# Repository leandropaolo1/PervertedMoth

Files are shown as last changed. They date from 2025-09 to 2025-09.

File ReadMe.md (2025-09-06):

# Perverted Moth – SLINO Design Files

This repository collects the **SLINO design files** and community discussion surrounding the experimental *Perverted Moth* sailing dinghy project.

The SLINO was a home-built International Moth concept — a carbon and foam “plate moth” constructed from router-cut panels and frames, assembled on an MDF jig. The project and build logs were originally shared on [Sailing Anarchy Forums](https://forums.sailinganarchy.com/threads/perverted-moth.89686/) :contentReference[oaicite:0]{index=0} and the [Perverted Moth Blog](http://perverted-moth.blogspot.com/search/label/slino).

---

## Preview

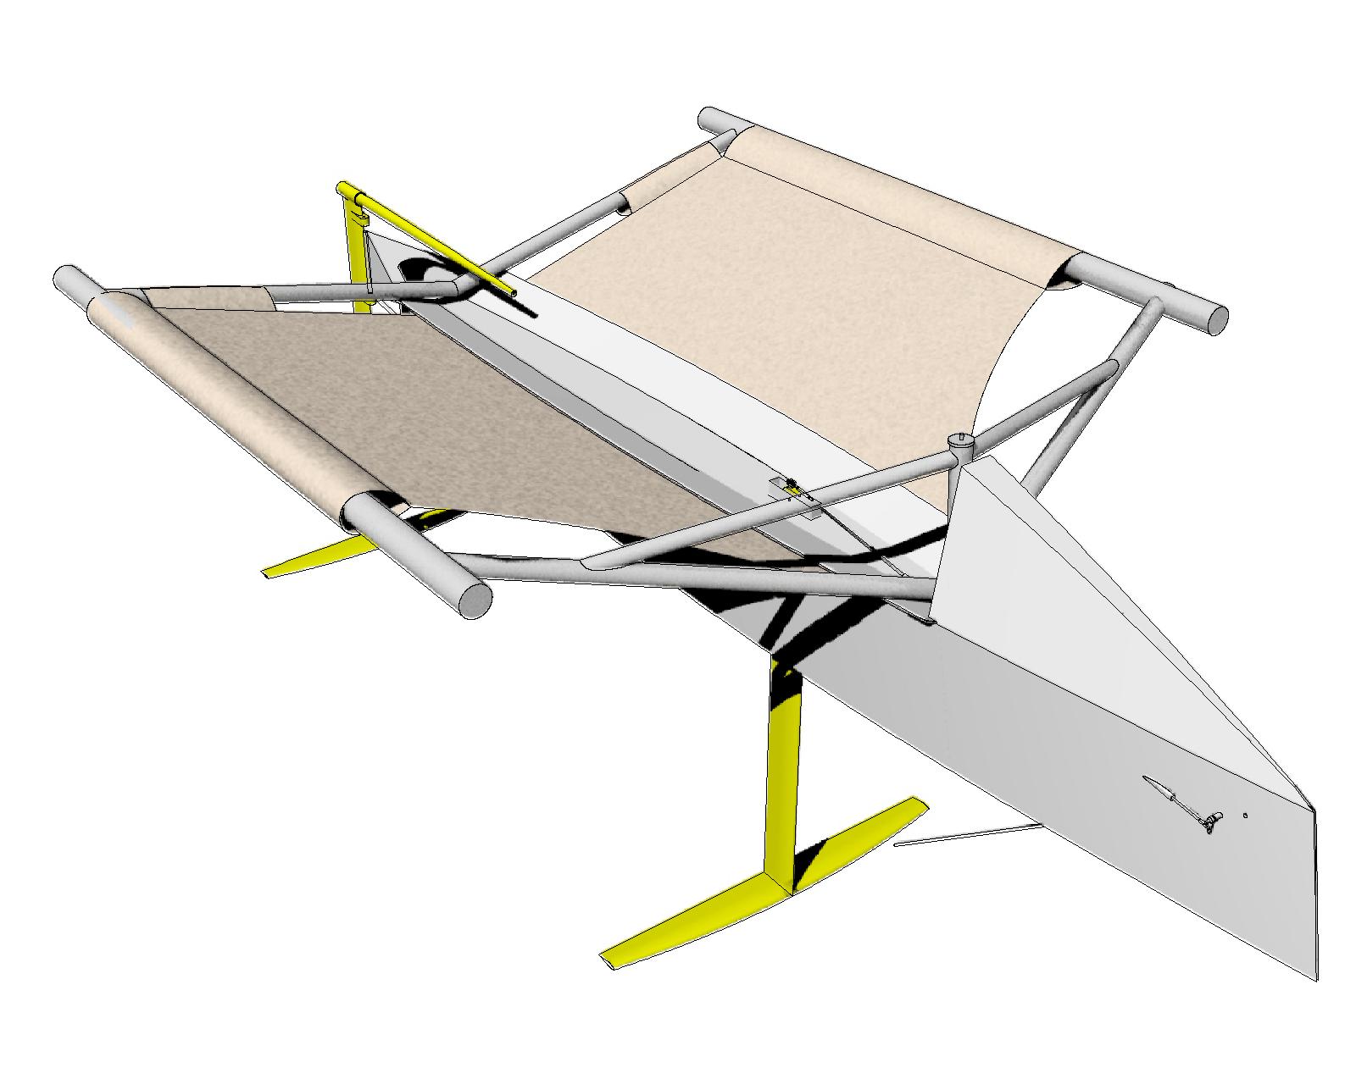
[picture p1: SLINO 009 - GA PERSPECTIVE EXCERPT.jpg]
SLINO GA Perspective Excerpt


*General Arrangement Perspective (excerpt)*

---

## ⚠️ Disclaimer

These files are published as a **personal reference only**.  
They are not guaranteed to be complete, safe, or production-ready.

- **No warranty is provided.**  
- **Use at your own risk.**  
- Building and sailing a moth to this design could seriously hurt you, cost you money, or cause emotional damage:contentReference[oaicite:1]{index=1}.  

If you attempt to replicate or derive from this design, please share your results with the original author (see below).

---

## Contents

The SLINO design package includes:

- **Documents & Calculations**  
  - Build sequence, parts list, weight estimate  
  - Hydrostatics and resistance predictions  

- **Drawings**  
  - Hull lines and construction details  
  - Centreboard, rudder, gantry, spreaders  
  - Wing and control system arrangements  

- **Cut Files & Jig**  
  - Carbon cut files  
  - MDF cut files  
  - Hull and deck panel marking  

- **3D Rhino Models**  
  - Hull construction and jig  
  - Wings, centreboard, rudder  
  - Wing sail, cradle, control system  

---

## References

- Blog archive: [perverted-moth.blogspot.com](http://perverted-moth.blogspot.com/search/label/slino)  
- Forum thread: [Sailing Anarchy – Perverted Moth](https://forums.sailinganarchy.com/threads/perverted-moth.89686/) :contentReference[oaicite:2]{index=2}  
- Original design files post: [SLINO Design Files (2010)](https://perverted-moth.blogspot.com/2010/11/slino-design-files.html) :contentReference[oaicite:3]{index=3}

---

## Contact

The design files were shared by **Markla (n4rkla)**.  
If you experiment with these designs, you are encouraged to send results or build logs to:

📧 **mr.markla@gmail.com**:contentReference[oaicite:4]{index=4}

---

## License

This project is **not licensed** for commercial use.  
Files are provided *as-is* for reference, experimentation, and historical interest.

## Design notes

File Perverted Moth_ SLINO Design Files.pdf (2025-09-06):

Sunday, November 14, 2010

## SLINO Design Files

Please Note:
I am publishing this information as a personal reference only. If you chose to replicate it, it is at your own risk. This information carries no warranty and has not been thoroughly thought through or engineered. Building and sailing a moth to this design could seriously hurt you and/or cost you a lot of money and/or cause emotional damage.

If you do attempt to replicate derivate from this information please send me an email – I am always interested to see where this design leads. (mr.markla@gmail.com)

See Also:
http://perverted-moth.blogspot.com/2009/01/new-moth-design.html

Documents and Calculations
SL2-A1-01A - Drawing and Document List (https://docs.google.com/uc?export=download&authkey=CN-VgPIJ&hl=en)
SL2-A1-02A - SLINO Build Sequence (https://docs.google.com/uc?export=download&authkey=CNLG-LgK&hl=en) SL2-A1-03 - Parts List
SL2-B1-01 - Weight Estimate (https://docs.google.com/open?id=0B2AmITOPvYs3YjllM2UwZjEtNGI4Ni00YWUwLWJhY2EtNWJhNjgxMDQ1ZTFj)
SL2-B2-01 - Table of Hydrostatics (https://docs.google.com/open?id=0B2AmITOPvYs3MDE4MTIzOTItMmE5Zi00ZGQ1LWEzYTUtMzUyZGFhMmE2NmFl) SL2-B2-02 - Resistance Prediction (https://docs.google.com/open?id=0B2AmITOPvYs3OTdkZGM3MGQtNTlhZC00MGI1LTg4NjItY2FhZDk2NGU4MjJh)

Drawings
SL2-C1-01 Side Profile Drawing SL2-C1-02A - General Arrangement (https://docs.google.com/uc?export=download&authkey=CK3E1asO&hl=en)

SL2-D1-01A - Hull Lines Drawing (https://docs.google.com/uc?export=download&authkey=COr-_s8G&hl=en)

SL2-E1-01A - Hull Construction Drawing (https://docs.google.com/uc?export=download&authkey=CNz7gcMD&hl=en) SL2-E1-02__04A - Hull Construction Details (https://docs.google.com/viewer?a=v&pid=explorer&chrome=true&hl=en_US) SL2-E2-01__02A - Centreboard Construction Drawing (https://docs.google.com/viewer?a=v&pid=explorer&chrome=true&hl=en_US) SL2-E3-01 Stem and Transom Lug Construction Details (https://docs.google.com/viewer?a=v&pid=explorer&chrome=true&hl=en_US) SL2-E4-01 Wing Mounts Construction Details (https://docs.google.com/viewer?a=v&pid=explorer&chrome=true&hl=en_US)

SL2-F1-01A - Wing Assembly (https://docs.google.com/uc?export=download&hl=en)
SL2-F2-01A - Gantry Construction Drawing (https://docs.google.com/uc?export=download&authkey=CLfcmI8G&hl=en) SL2-F3-01A - Spreader Construction Drawing (https://docs.google.com/uc?export=download&authkey=CNL18sgL&hl=en) SL2-F4-01A - Running Rigging Arrangement (https://docs.google.com/viewer?a=v&pid=explorer&chrome=true&hl=en_US) SL2-F5-01__02A - Cradle Arrangement (https://docs.google.com/uc?export=download&authkey=CNLH6WQ&hl=en)

SL2-G1-01A - Control System Arrangement (https://docs.google.com/viewer?a=v&pid=explorer&chrome=true&hl=en_US) SL2-G1-02A - Control System Parts (https://docs.google.com/viewer?a=v&pid=explorer&chrome=true&hl=en_US)

Click to jump to the design post.

SLINO

This site has a lot of weird content. If you want to view only posts regarding the design and build of the SLINO design, click the picture.

SLINO FILTER

MARKLA (https://www.blogger.com/profile/16777292264295936655)

n4rkla (https://www.blogger.com/profile/01014271006445643045)

CONTRIBUTORS

- 2017 (https://perverted-moth.blogspot.com/2017/) (1)
- 2015 (https://perverted-moth.blogspot.com/2015/) (3)
- 2014 (https://perverted-moth.blogspot.com/2014/) (3)
- 2013 (https://perverted-moth.blogspot.com/2013/) (19)
- 2012 (https://perverted-moth.blogspot.com/2012/) (18)
- 2011 (https://perverted-moth.blogspot.com/2011/) (21)

▼ 2010 (https://perverted-moth.blogspot.com/2010/) (35)
- December (https://perverted-moth.blogspot.com/2010/12/) (1)

Blog Archive

More | Create Blog (https://www.blogger.com/onboarding) Sign In (https://www.blogger.com/)

Posted by MARKLA (https://www.blogger.com/profile/16777292264295936655) at 8:54 PM (https://perverted-moth.blogspot.com/2010/11/slino-design-files.html) Labels: design, (https://perverted-moth.blogspot.com/search/label/design) slino (https://perverted-moth.blogspot.com/search/label/slino)

SL2-H1-01A - Hull Jig Assembly (https://docs.google.com/uc?export=download&authkey=CKD--tEP&hl=en) SL2-H1-02A - Deck Jig Assembly (https://docs.google.com/uc?export=download&authkey=CNO9yMAD&hl=en) SL2-H1-03A - Foredeck Jig Modification (https://docs.google.com/uc?export=download&authkey=CKOhy74L&hl=en)

SL2-I1-01A - Carbon Cut File (1) SL2-I1-02A - Carbon Cut File (2) (https://docs.google.com/uc?export=download&authkey=CP3i0JYM&hl=en) SL2-I2-01A - MDF Cut File (1) SL2-I2-02A - MDF Cut File (2) (https://docs.google.com/uc?export=download&authkey=CJm_-Y4K&hl=en) SL2-I3-01A - Hull Panel Marking (https://docs.google.com/uc?export=download&authkey=CNnmnr8N&hl=en) SL2-I3-02A - Deck Panel Marking (https://docs.google.com/uc?export=download&authkey=CJjL29gC&hl=en)

Rhino Models
All models have the same zero point, so you can import (or worksession) the components into a single file. SL2-R1-01A - Hull Construction (https://docs.google.com/uc?export=download&authkey=CJyo3bUF&hl=en)
SL2-R1-02A - Hull Jig (https://docs.google.com/uc?export=download&authkey=CMfQ6awO&hl=en)
SL2-R1-03A - Wings (https://docs.google.com/uc?export=download&authkey=CNzQxsgL&hl=en)

SL2-R2-01A - Centreboard (https://docs.google.com/uc?export=download&authkey=CM_9-5oH&hl=en)

SL2-R3-01A - Rudder (https://docs.google.com/uc?export=download&authkey=CJn_7rkB&hl=en)

SL2-R4-01A - Control System (https://docs.google.com/uc?export=download&authkey=CMWgyMQJ&hl=en)

SL2-R5-01A - Wing Sail (https://docs.google.com/uc?export=download&authkey=CIyVoc0M&hl=en)

SL2-R9-01A - Cradle (https://docs.google.com/uc?export=download&authkey=CJiKxfME&hl=en)

## 6 comments:

Anonymous November 15, 2010 at 1:52 PM (https://perverted-moth.blogspot.com/2010/11/slino-design-files.html?showComment=1289793150781)

Very cool! Thanks.

Reply

Anonymous November 16, 2010 at 10:52 AM (https://perverted-moth.blogspot.com/2010/11/slino-design-files.html?showComment=1289868720213)

Funny about the Wing sail link.....

Reply

n4rkla (https://www.blogger.com/profile/01014271006445643045) November 16, 2010 at 9:46 PM (https://perverted-moth.blogspot.com/2010/11/slino-design-files.html?showComment=1289907984469)

oh hardy har har...I'll get you for that pikey

Reply

trentpt17 (https://www.blogger.com/profile/12523880471407403194) July 18, 2011 at 12:41 AM (https://perverted-moth.blogspot.com/2010/11/slino-design-files.html?showComment=1310913688922)

This comment has been removed by the author.

▼ November (https://perverted-moth.blogspot.com/2010/11/) (7)
what would tucker do? (https://perverted-moth.blogspot.com/2010/11/what-would-tucker-do.html)

Hat-trick! (https://perverted-moth.blogspot.com/2010/11/hat-trick.html)

Luka's Lister Boom (https://perverted-moth.blogspot.com/2010/11/lukas-boom.html)

wing rule idea (https://perverted-moth.blogspot.com/2010/11/wing-rule-idea.html)

nick in teh boat (https://perverted-moth.blogspot.com/2010/11/nick-in-teh-boat.html)

Wanted (https://perverted-moth.blogspot.com/2010/11/wanted.html)

SLINO Design Files (https://perverted-moth.blogspot.com/2010/11/slino-design-files.html)

- October (https://perverted-moth.blogspot.com/2010/10/) (2)
- August (https://perverted-moth.blogspot.com/2010/08/) (2)
- July (https://perverted-moth.blogspot.com/2010/07/) (3)
- June (https://perverted-moth.blogspot.com/2010/06/) (2)
- May (https://perverted-moth.blogspot.com/2010/05/) (1)
- April (https://perverted-moth.blogspot.com/2010/04/) (3)
- March (https://perverted-moth.blogspot.com/2010/03/) (3)
- February (https://perverted-moth.blogspot.com/2010/02/) (7)
- January (https://perverted-moth.blogspot.com/2010/01/) (4)
- 2009 (https://perverted-moth.blogspot.com/2009/) (79)
- 2008 (https://perverted-moth.blogspot.com/2008/) (6)

Counter?

Newer Post (https://perverted-moth.blogspot.com/2010/11/wanted.html) | Home (https://perverted-moth.blogspot.com/) | Older Post (https://perverted-moth.blogspot.com/2010/10/weather-at-belmont.html)

Subscribe to: Post Comments (Atom) (https://perverted-moth.blogspot.com/feeds/4189133828921951536/comments/default)

Enter Comment

Reply

Doug Culnane (https://www.blogger.com/profile/03539164499743848586) October 26, 2011 at 9:35 PM (https://perverted-moth.blogspot.com/2010/11/slino-design-files.html?showComment=1319628926761)

Great work. I have added a link here: http://www.moth-sailing.org/imca/faces/HomeBuild.jsp

Reply

Anonymous February 20, 2012 at 11:52 PM (https://perverted-moth.blogspot.com/2010/11/slino-design-files.html?showComment=1329745979340)

THANK YOU!! been looking for a project to build with the kids! finally, someone that's willing to share their extensive knowledge :)

if i ever complete it.. ill name her SLINO and send you youtube links of us getting VERY wet lol

Reply

weather

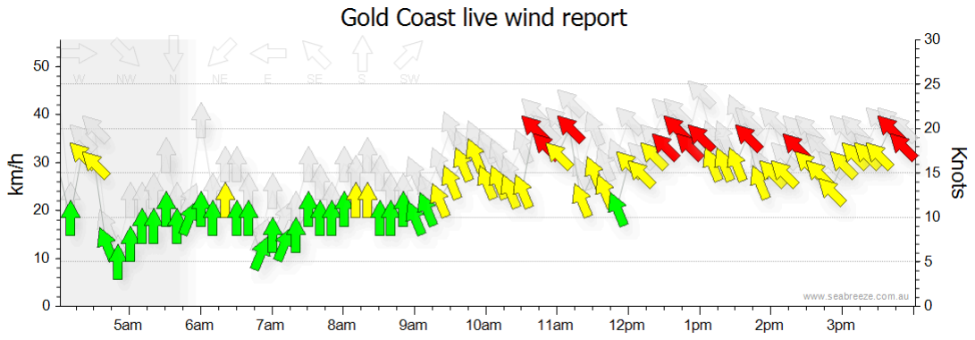
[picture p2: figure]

Awesome Inc. theme. Powered by Blogger. (https://www.blogger.com/)

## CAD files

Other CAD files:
Files/SL2-R1-01A - HULL CONSTRUCTION.3dm
Files/SL2-R1-03A - WINGS.3dm
Files/SL2-R2-01A - CENTREBOARD.3dm
Files/SL2-R3-01A - RUDDER.3dm
Files/SL2-R4-01A - CONTROL SYSTEM.3dm
Files/SL2-R9-01A - CRADLE.3dm

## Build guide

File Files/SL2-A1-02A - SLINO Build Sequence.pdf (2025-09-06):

SL2-A1-02A | SLINO Build Sequence
Markla | 11.11.10
This boat was designed for a very fast build. As such below you will see a number of phases with concurrent tasks. You can jump between these concurrent tasks while waiting for resin to cure etc, or if you are lucky enough to have friends or slaves they can be working on the concurrent tasks. Generally you will need to complete all tasks within a phase before moving on to the next one.
Where possible, don’t let resin cure where you need to overlaminate it later. For example on the inner seams on the hull, aim to cove seam, tape seam, drop in frames, cove frames and tape frames all before the initial cove has cured. Slow hardner and an extra set of hands helps. If you can achieve this, no sanding is required prior to the fairing procedure which is nice.
I am publishing this information as a personal reference only. If you chose to replicate it, it is at your own risk.
This information carries no warranty and has not been thoroughly thought through or engineered.
Building and sailing a moth to this design could seriously hurt you.
If you do attempt to replicate derivate from this information please send me an email – I am always interested to see where this design leads.
mr.markla@gmail.com
Phase | Concurrent Tasks
0 Order cut parts | Order materials Order consumables Order wing tubes | Get tools Clean/setup work space | Laminate some solid laminate, 300x300x4.5mm should be ample. Include plenty of E glass in this laminate (80%) as it is harder wearing than carbon. | Read all notes Review all drawings Review all photos
1 Assemble Hull Jig | See Drawing SL2-H1-01 Assemble Deck Jig See Drawing SL2-H1-02 Assemble Foredeck Jig See Drawing SL2-H1-02 | Remove peel ply from: • Hull inside • Deck outside • Foredeck exterior seamsi Mark bulkhead locations on hull panels. See Drawing SL2-I3-01 Mark wand push rod penetrations on hull, deck and bulkhead parts. See Drawing SL2-I3-03 | Decore hull and deck panels around centreboard case. See Drawing SL2-E2-01 Decore centreboard case as required. See Drawing SL2-E2-01 Cut push rod and wand axle penetrations into hull, deck and bulkhead. See Drawing SL2-I3-03 | Build centreboard case. See Drawing SL2-E2-01 Insert solid laminate into stem piece and add Unis. See Drawing SL2-E3-01 Insert solid and add unis to into transom lugs. See Drawing SL2-E3-01

Phase | Concurrent Tasks
2 Insert hull panels into jig and hot glue to | frames. See Drawing SL2-E1-02 Test fit bulkheads and frames Laminate internal hull seams and stem piece. See Drawing SL2-E1-01 Immediately install and laminate: • Frames • Bulkheads • centreboard case • Transom • Transom lug. • Mast king post | Hot glue deck pieces to jig. Laminate external deck seams See Drawing SL2-E1-02 | Hot glue foredeck to jig Laminate external seams See Drawing SL2-E1-02 | Build wings See Drawing SL2-F1-01
3 Remove hull from jig | Trim peel ply 50mm from seams Laminate external seams. | Remove deck from jig Laminate internal seams | Remove foredeck from jig Laminate internal seams Add mast ram reinforcing inside foredeck. See Drawing SL2-E4-01 | Using transverse wing tube as a plug, mould up a 500mm long half tube in E glass (if alloy wings) or carbon for carbon wings.
4 Dremel perimeter of hull panels. | Dremel perimeter of foredeck. Dremel across each frame. Cut bung hole into transom, decore and back fill. | Glue deck on and laminate to hull. See Drawing SL2-E1-02 Concurrently build wing foundationsii See Drawing SL2-E4-01 Laminate deck to centreboard case. | | Cut wing half tubes into lengths for wing mounts and washer plates. See Drawing SL2-E4-01
5 | Insert wand axle and push rod conduit. | Glue foredeck on and laminate to hull and bulkhead. | Drop wings on and laminate wing mounts. See Drawing SL2-E4-01
6 Drill lacing holes for tramps. Decore and back | fill. Wipe fairing compound over all seams | Insert solid into gantry lugs and apply unis. See Drawing SL2-F2-01 | Assemble cradle See Drawing SL2-F5-01 | Build external mast ram. See Drawing SL2-E4-01
7 Redrill lacing holes. | Fair all seams. Patch fill with fairing compound | Laminate gantry external seams See Drawing SL2-F2-01 | Insert solid into spreaders and apply unis See Drawing SL2-F3-01 | Get tramps made.
8 Final fair seams. | Apply undercoat | Remove gantry from jig and laminate internal seams See Drawing SL2-F2-01 | Undercoat spreadersiii
9 Fit centreboard to hulliv | Assemble push rod system. See Drawing SL2-G1-01 | Apply clear coat | Top coat spreaders

Phase | Concurrent Tasks
10 | Apply top coat | Get shrouds made.
11 Pimp the boat with pulleys, ropes mast sail etc. | See Drawing SL2-F4-01 | Pull on lots of rig tension, downhaul, vang and mainsheet and hope nothing breaks. Fix it if it does.

12 Up for a sail?

Foot Notes:
i Only remove the peel ply from where the seam is going to go. Use a knife to score the peel ply 50mm away from the seam. Then only remove this 50mm strip of peel ply. This will preserve the carbon finish for painting/clear coating later. If you are really smart you can make a little machine that holds a knife blade 50mm away from a guide that follows the edge of the panel. This keeps a consistant 50mm.
ii Take special care and review this drawing. You need to wet out half of the uni and apply it to the inside of the hull before dropping the deck on. After immediately after dropping the deck on it needs to be folded over on top of the deck. This is a very delicate procedure and crucial for a good load transmission from the wings.
iii Don’t bother painting the gantry. Its going to break anyway.
iv I just added high density bog to my centreboard. Others have built cassettes that make up the difference. The choice is up to you.

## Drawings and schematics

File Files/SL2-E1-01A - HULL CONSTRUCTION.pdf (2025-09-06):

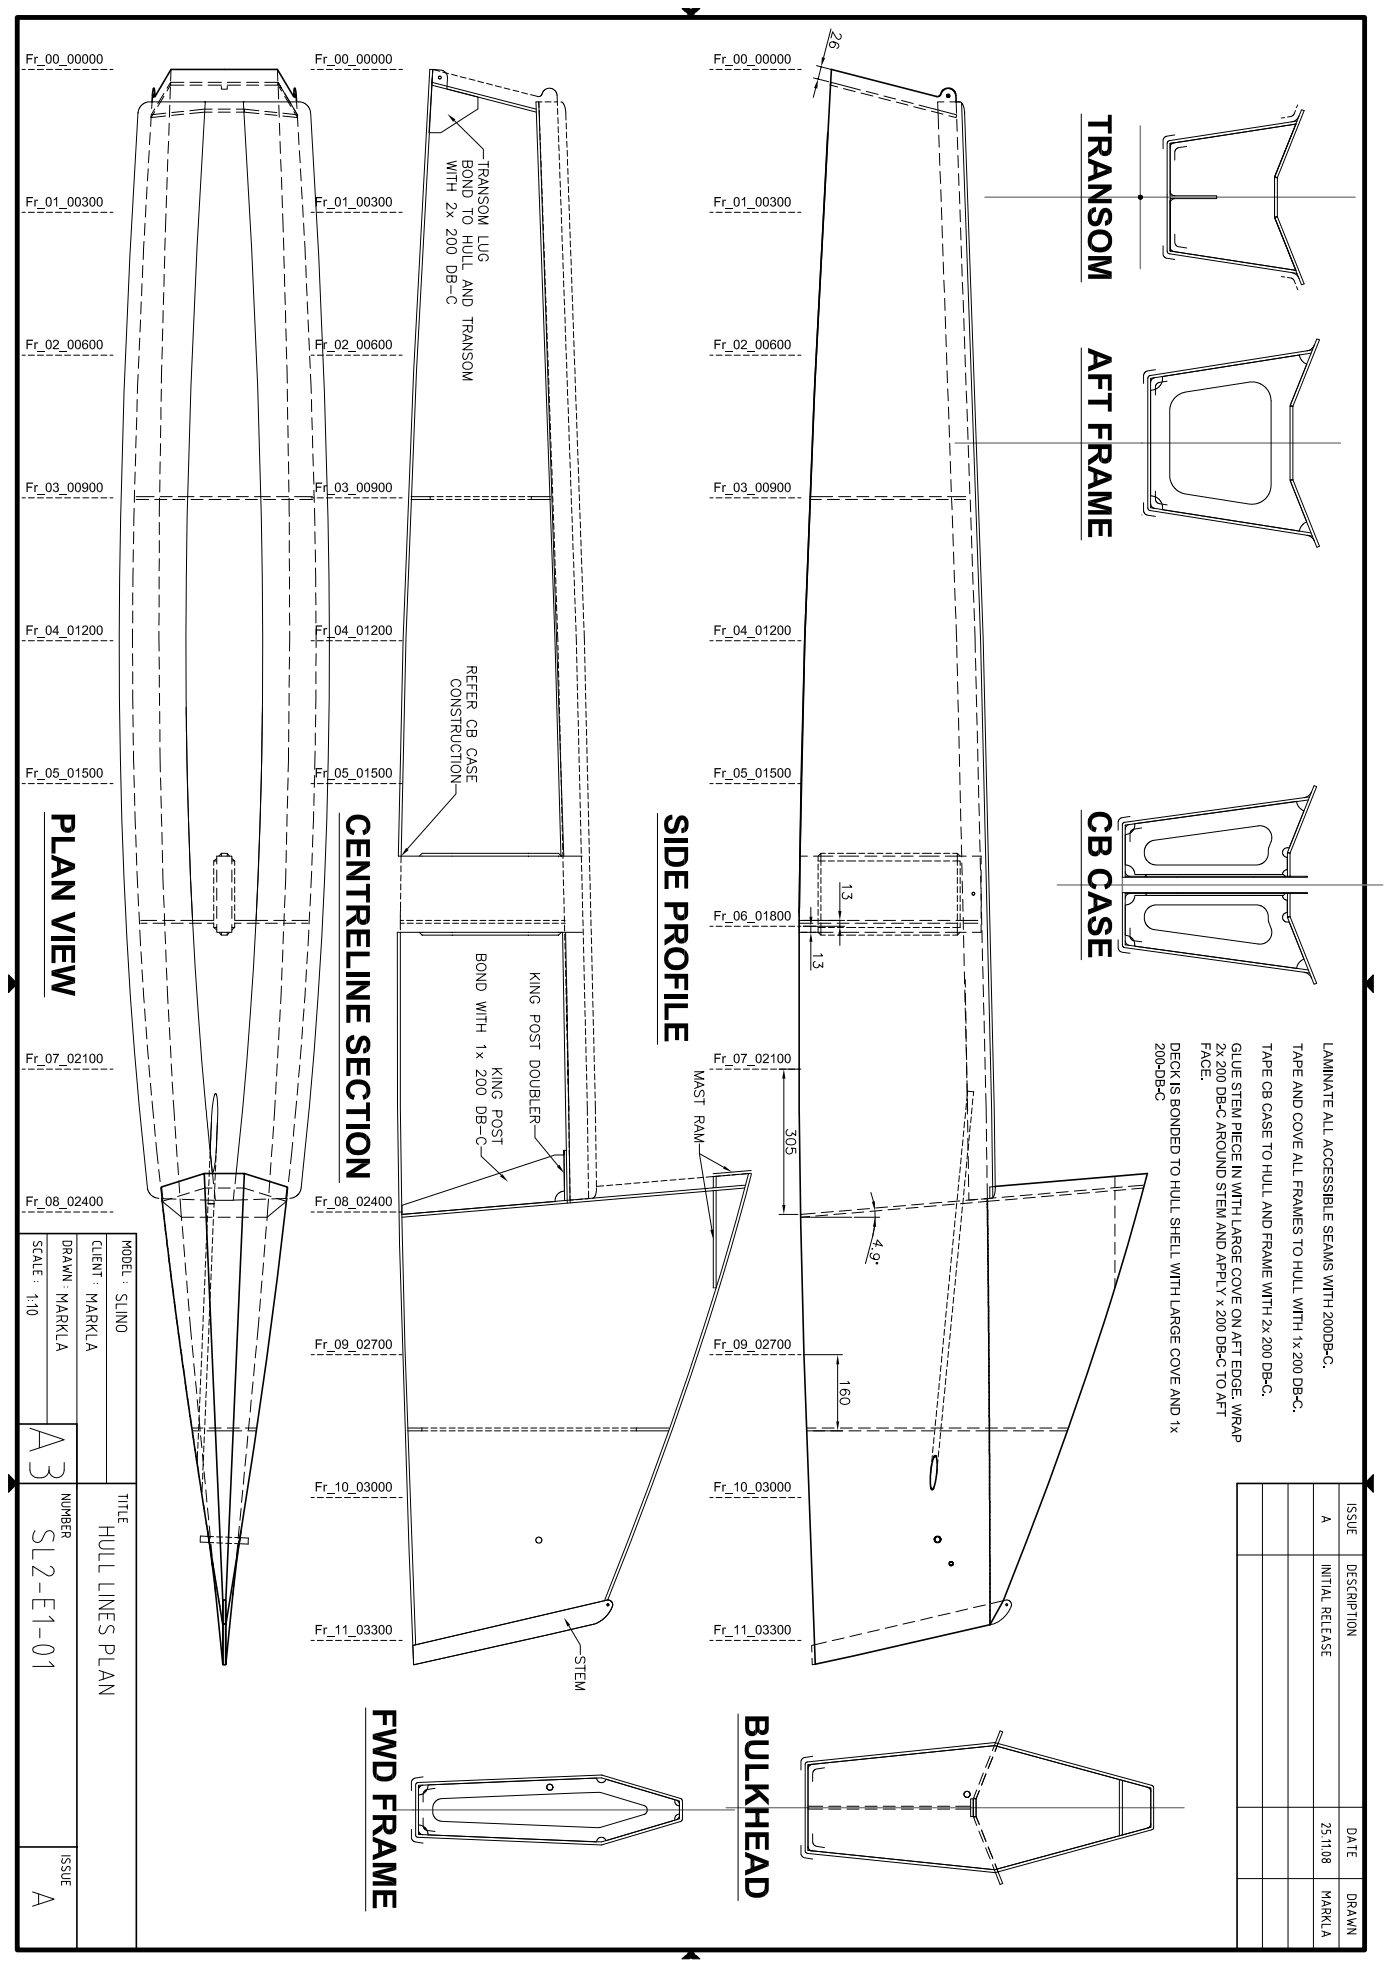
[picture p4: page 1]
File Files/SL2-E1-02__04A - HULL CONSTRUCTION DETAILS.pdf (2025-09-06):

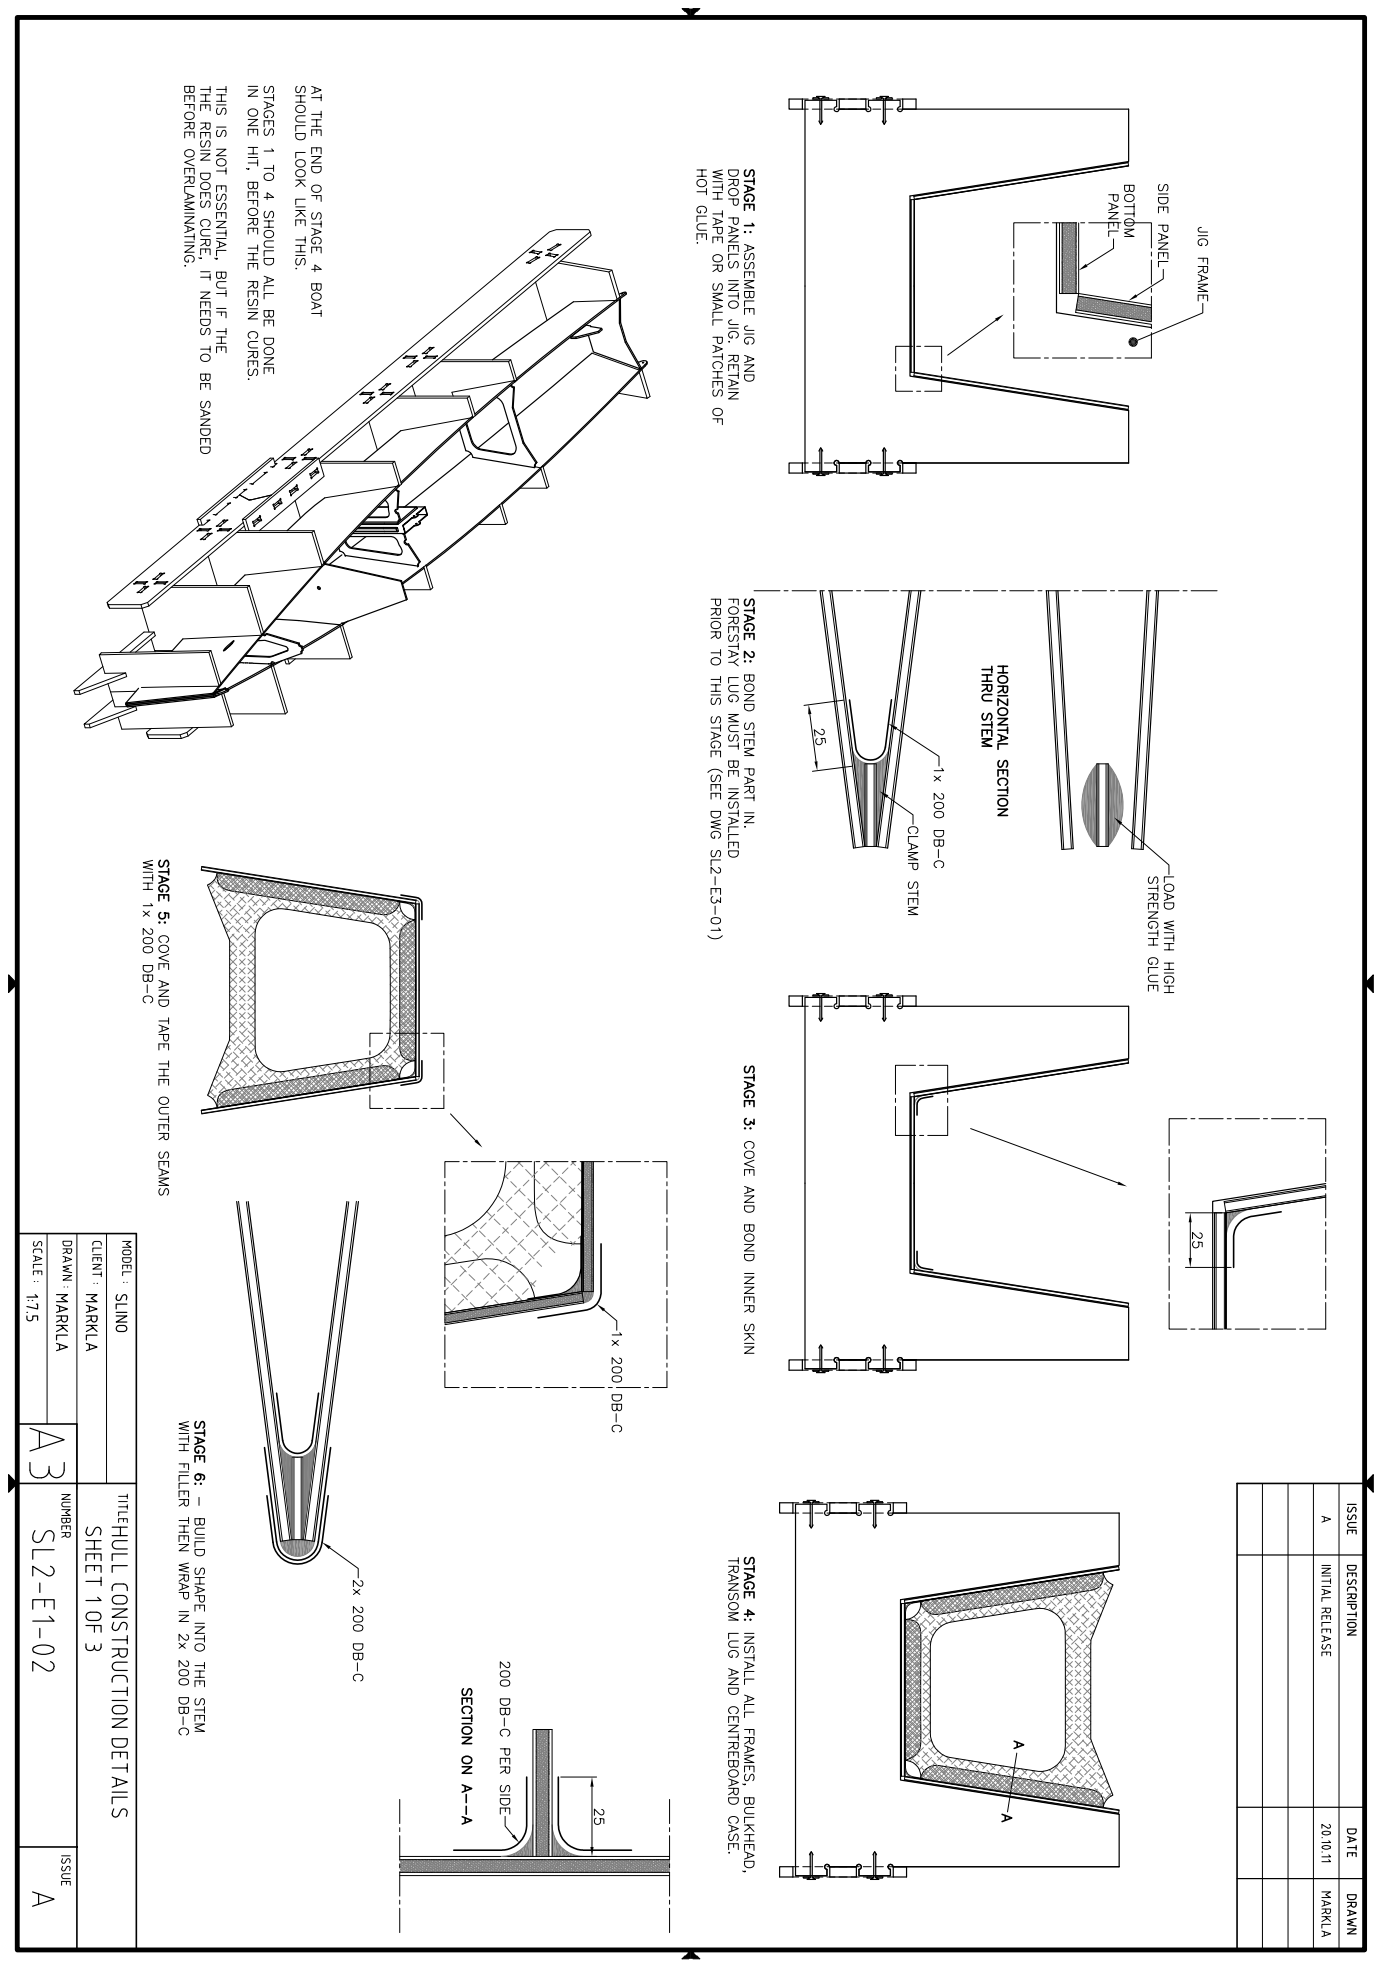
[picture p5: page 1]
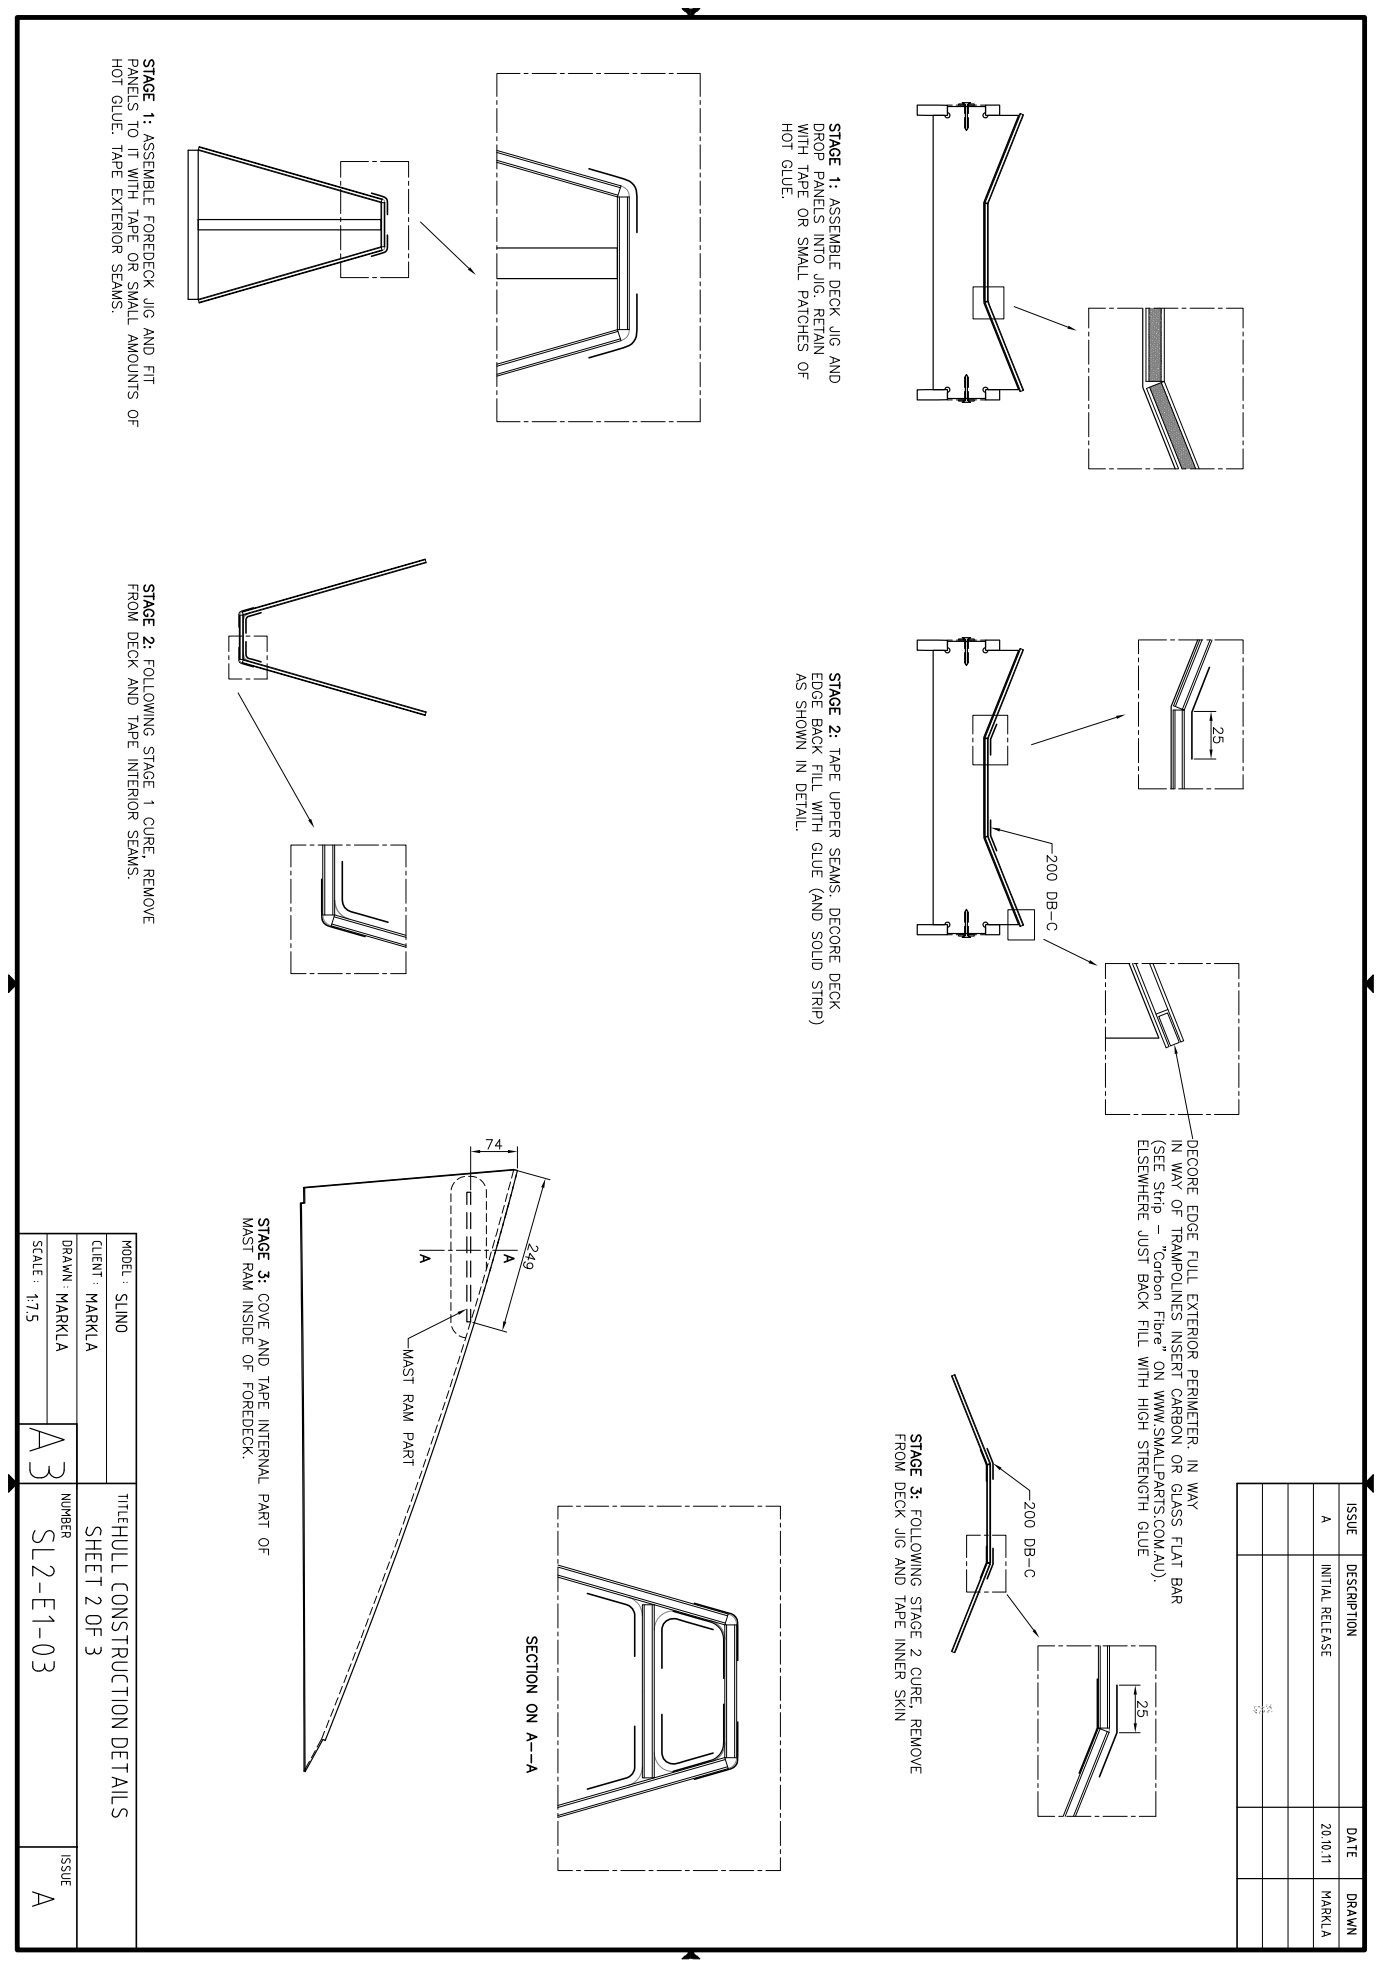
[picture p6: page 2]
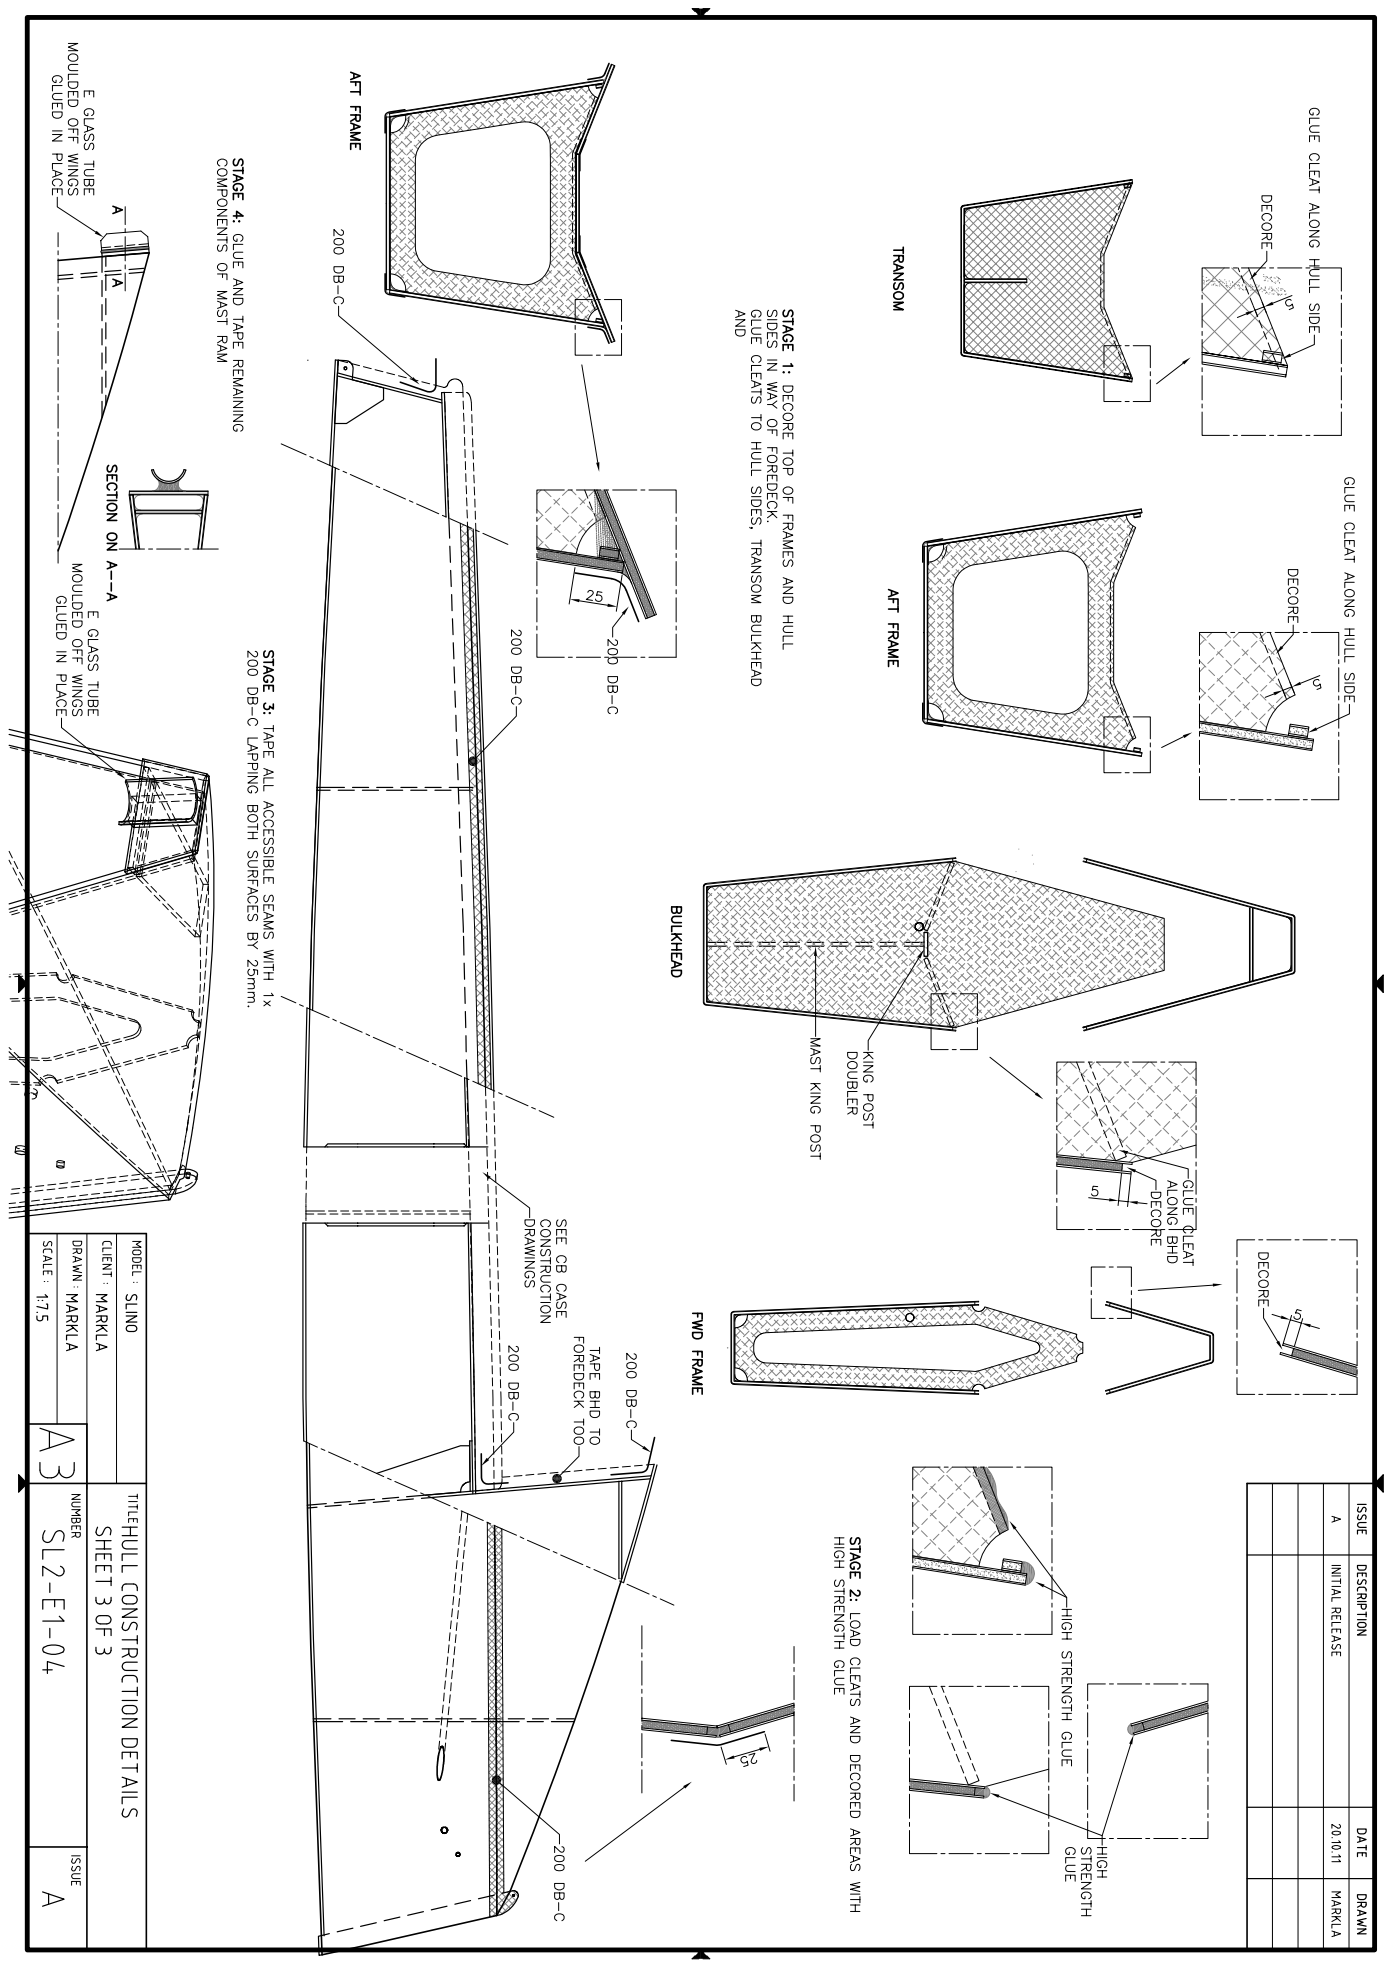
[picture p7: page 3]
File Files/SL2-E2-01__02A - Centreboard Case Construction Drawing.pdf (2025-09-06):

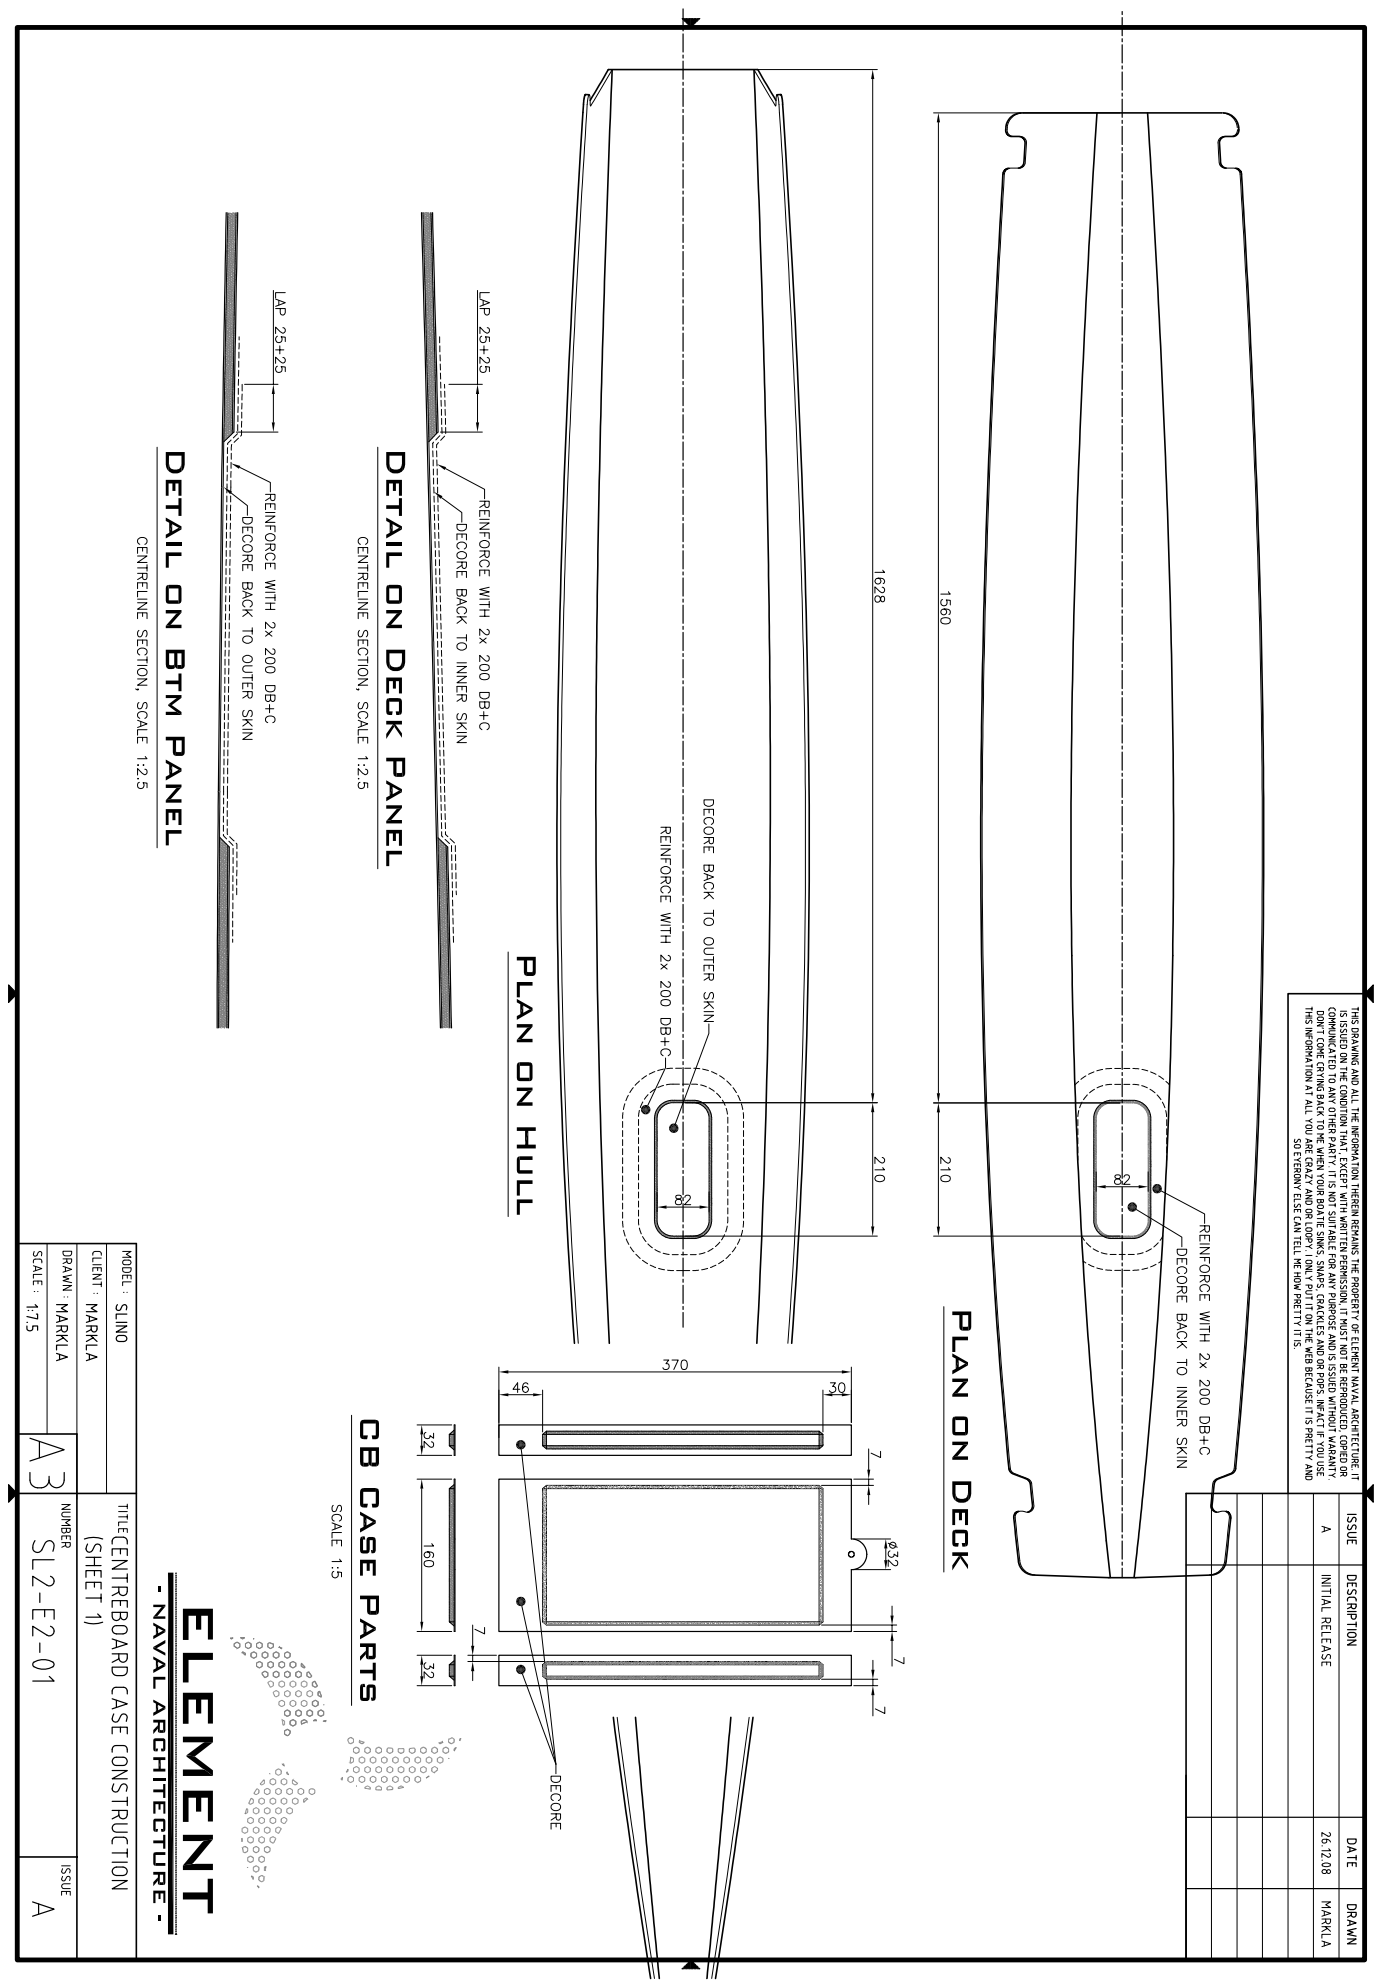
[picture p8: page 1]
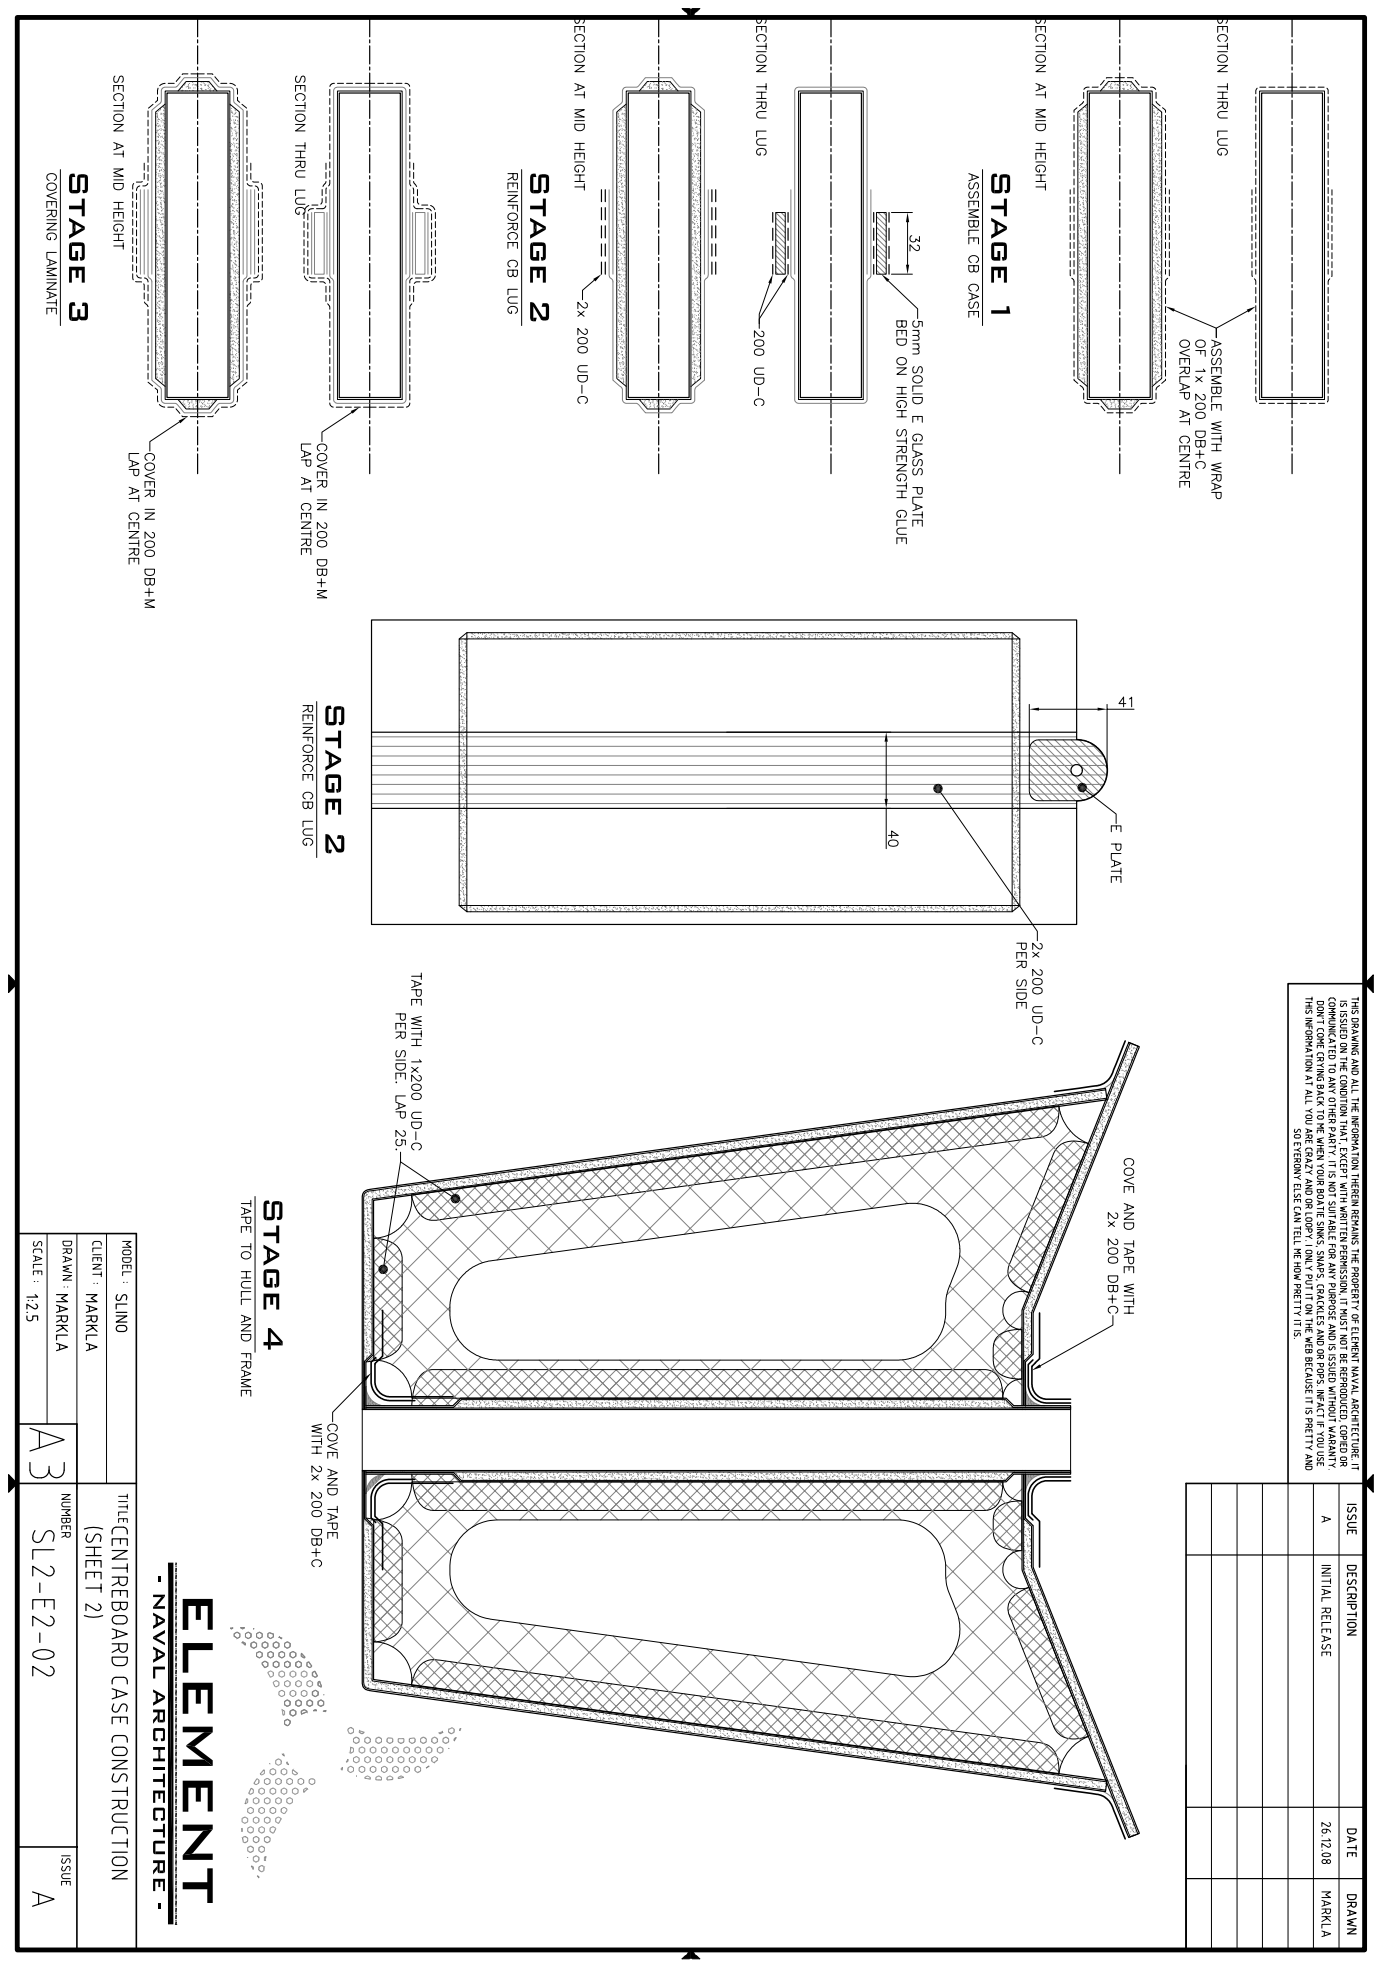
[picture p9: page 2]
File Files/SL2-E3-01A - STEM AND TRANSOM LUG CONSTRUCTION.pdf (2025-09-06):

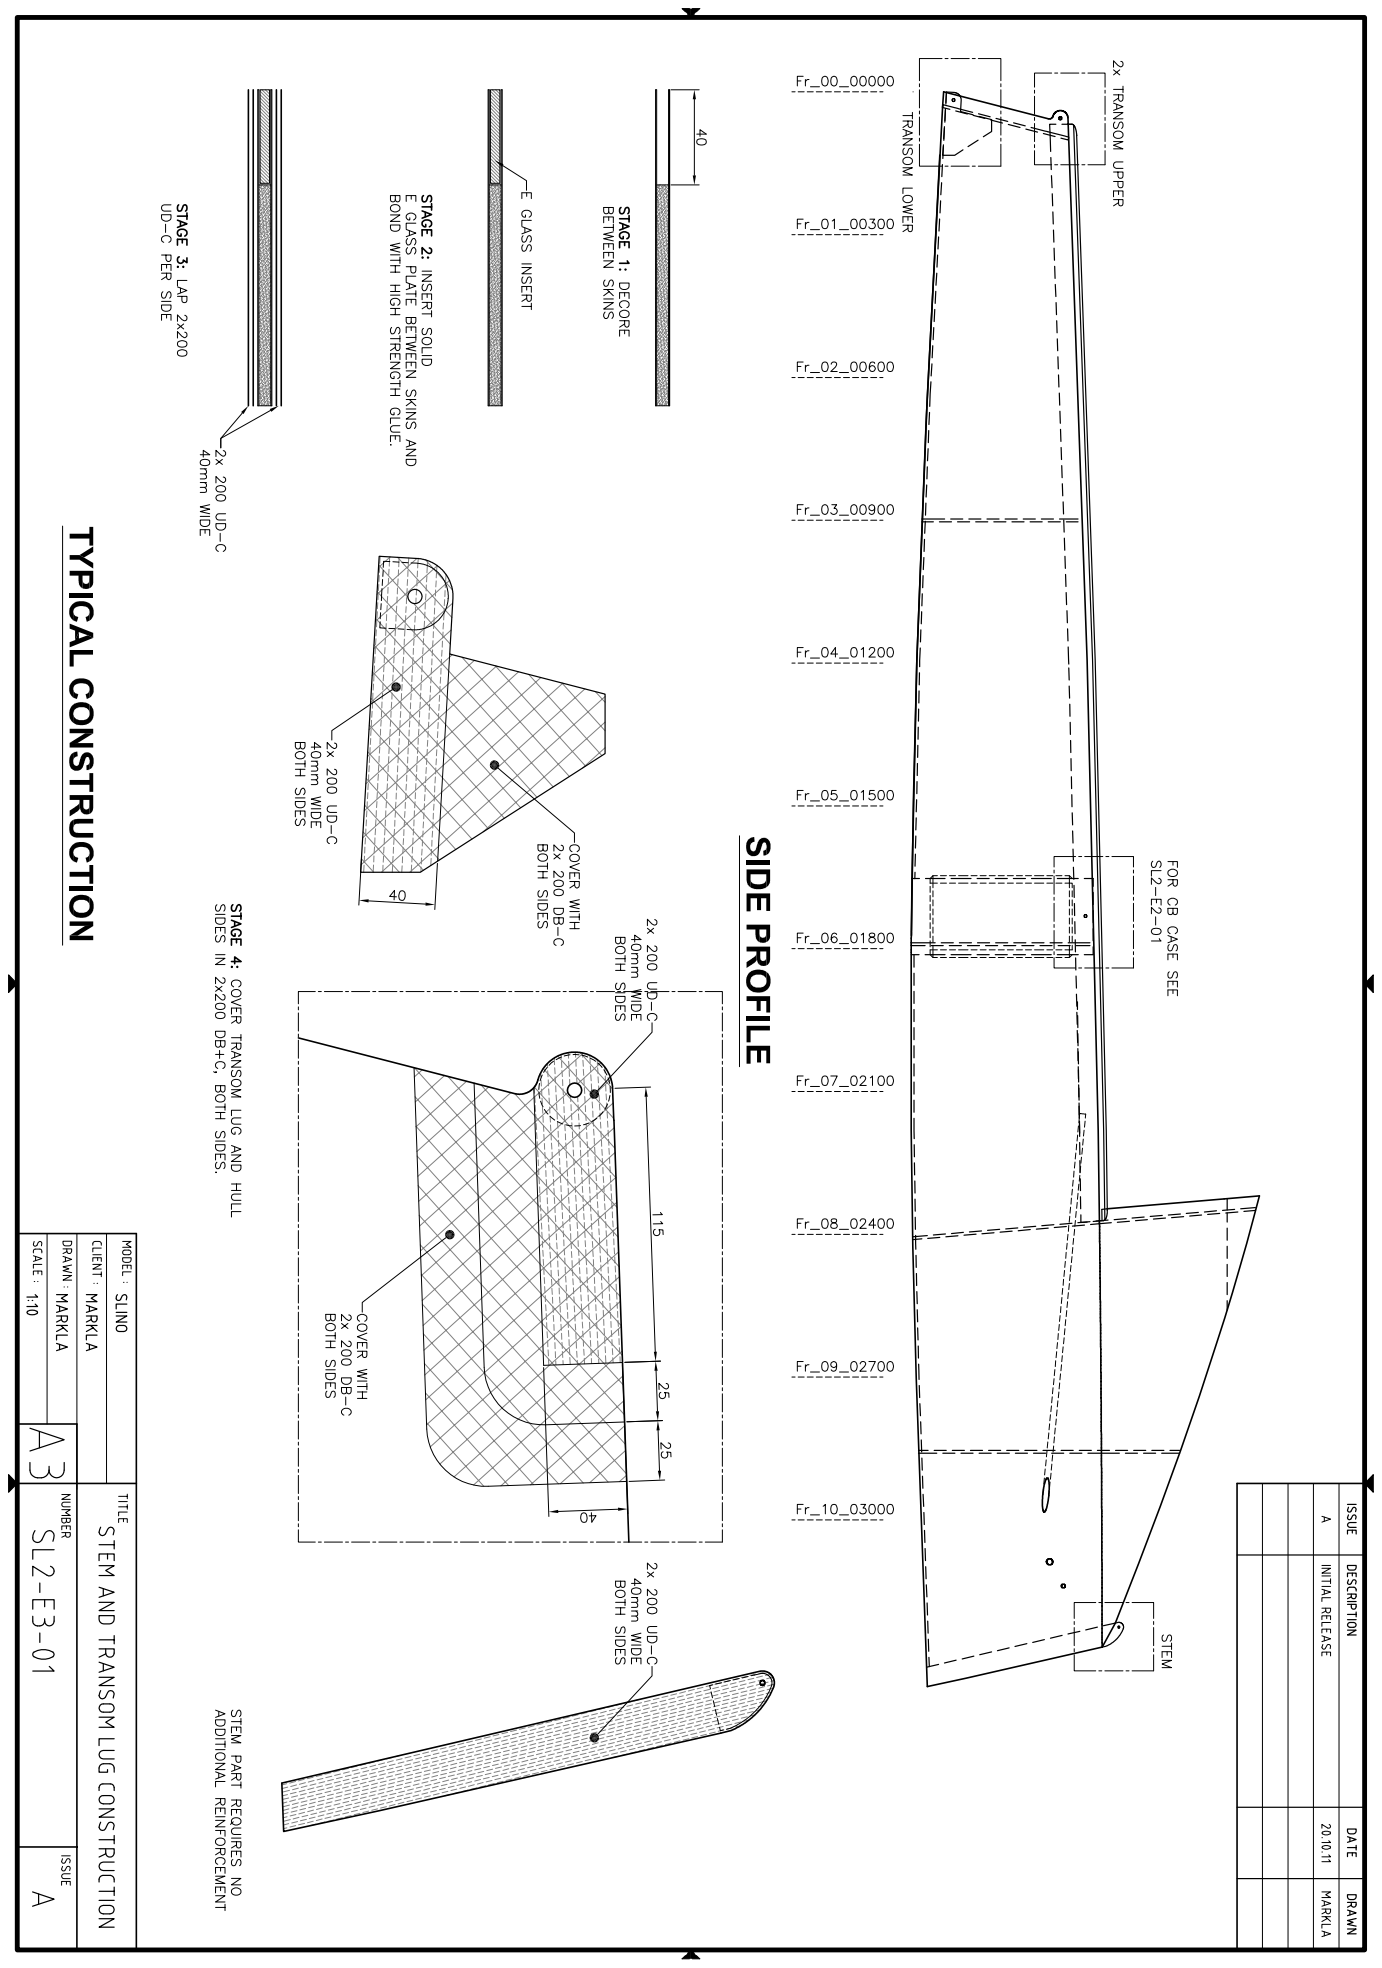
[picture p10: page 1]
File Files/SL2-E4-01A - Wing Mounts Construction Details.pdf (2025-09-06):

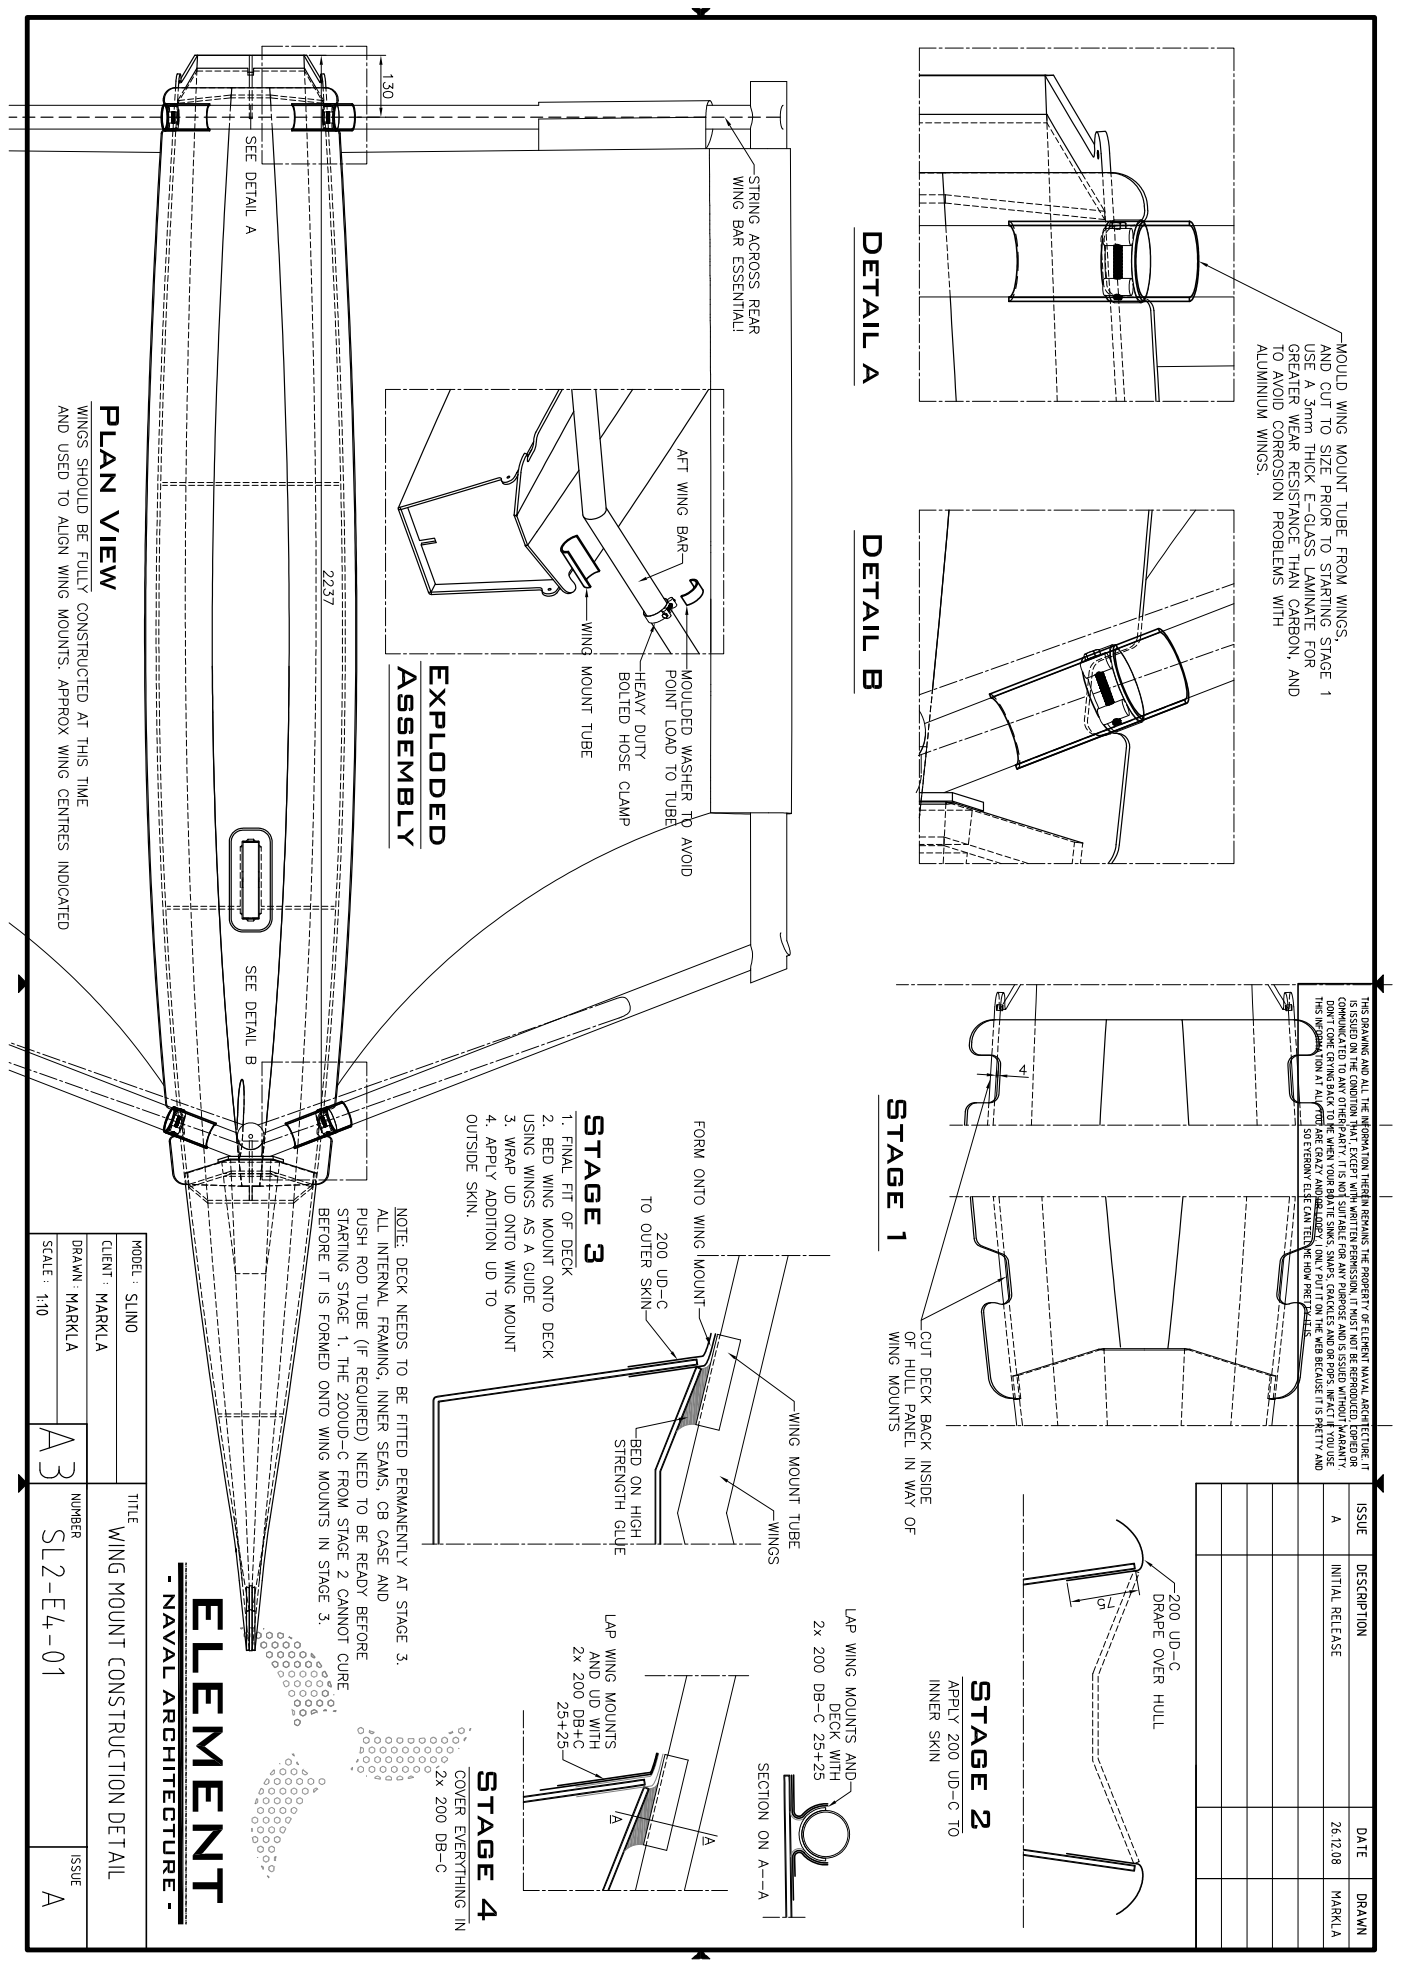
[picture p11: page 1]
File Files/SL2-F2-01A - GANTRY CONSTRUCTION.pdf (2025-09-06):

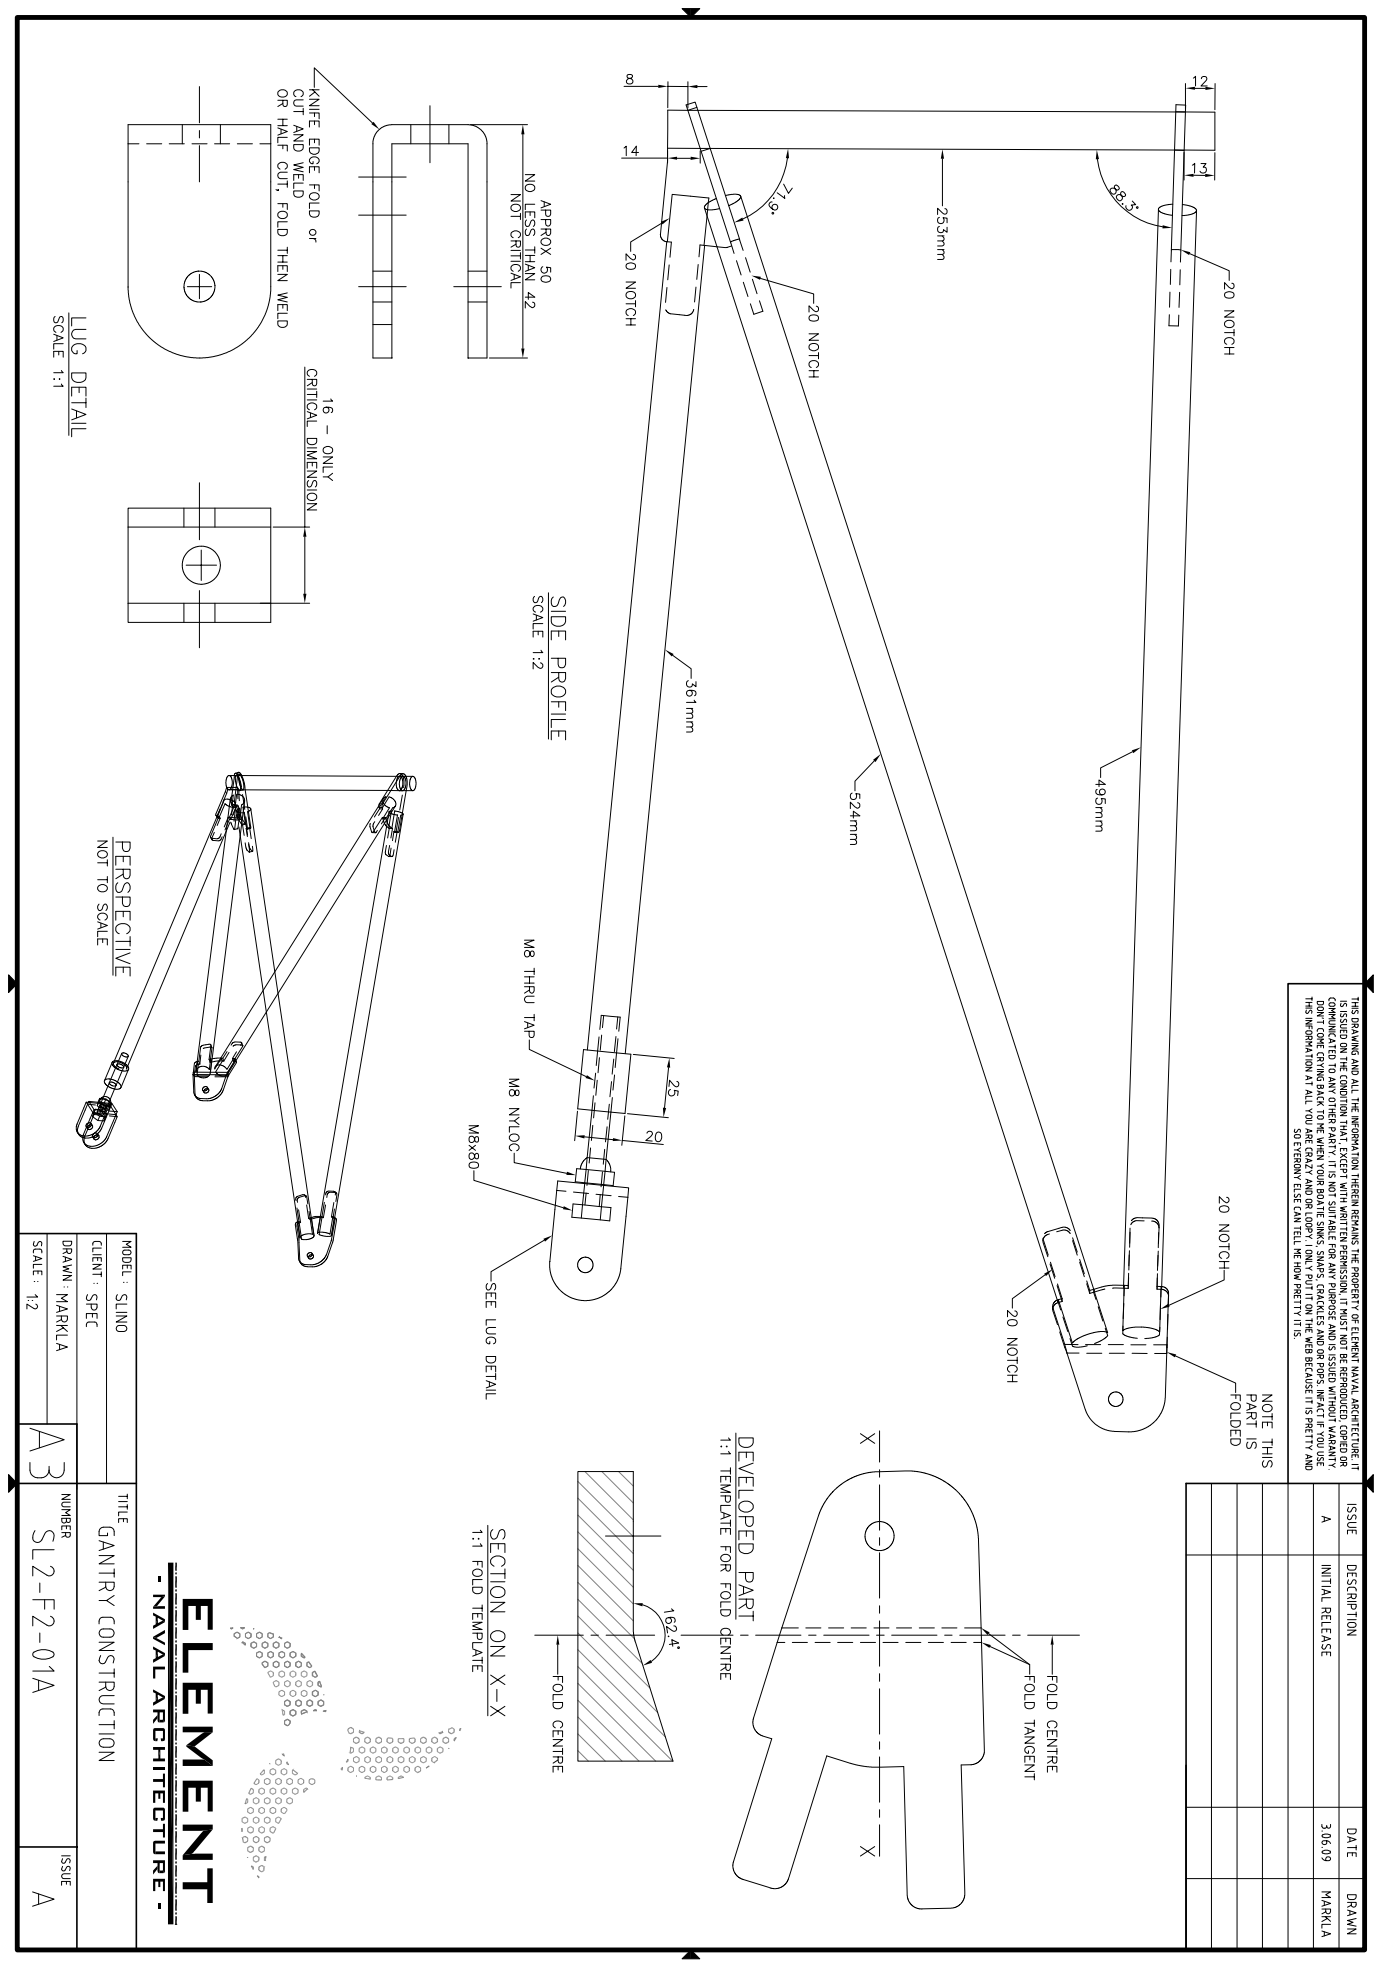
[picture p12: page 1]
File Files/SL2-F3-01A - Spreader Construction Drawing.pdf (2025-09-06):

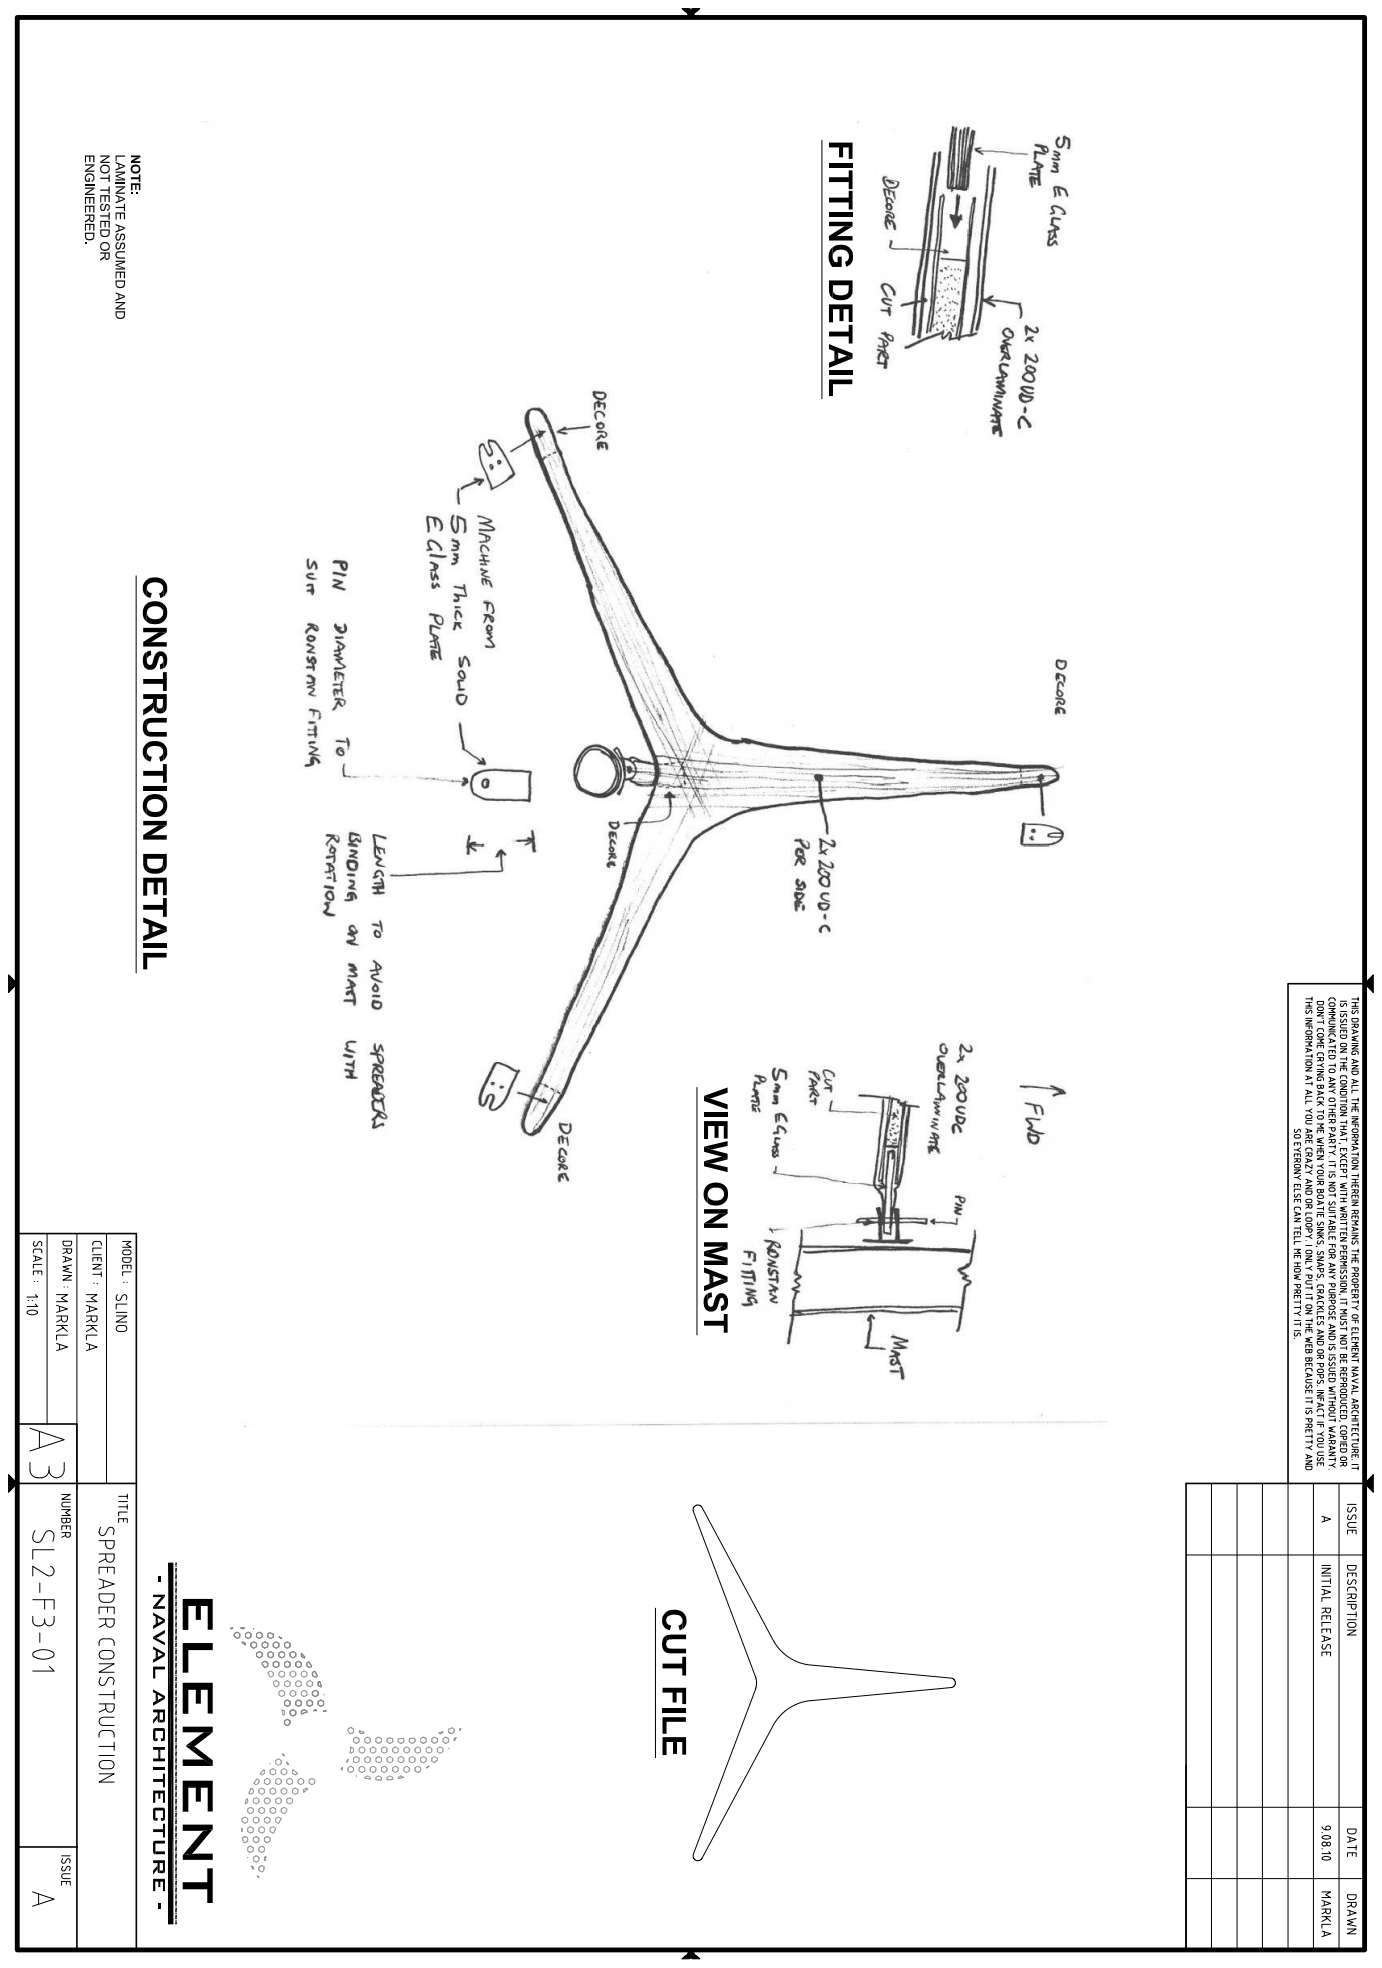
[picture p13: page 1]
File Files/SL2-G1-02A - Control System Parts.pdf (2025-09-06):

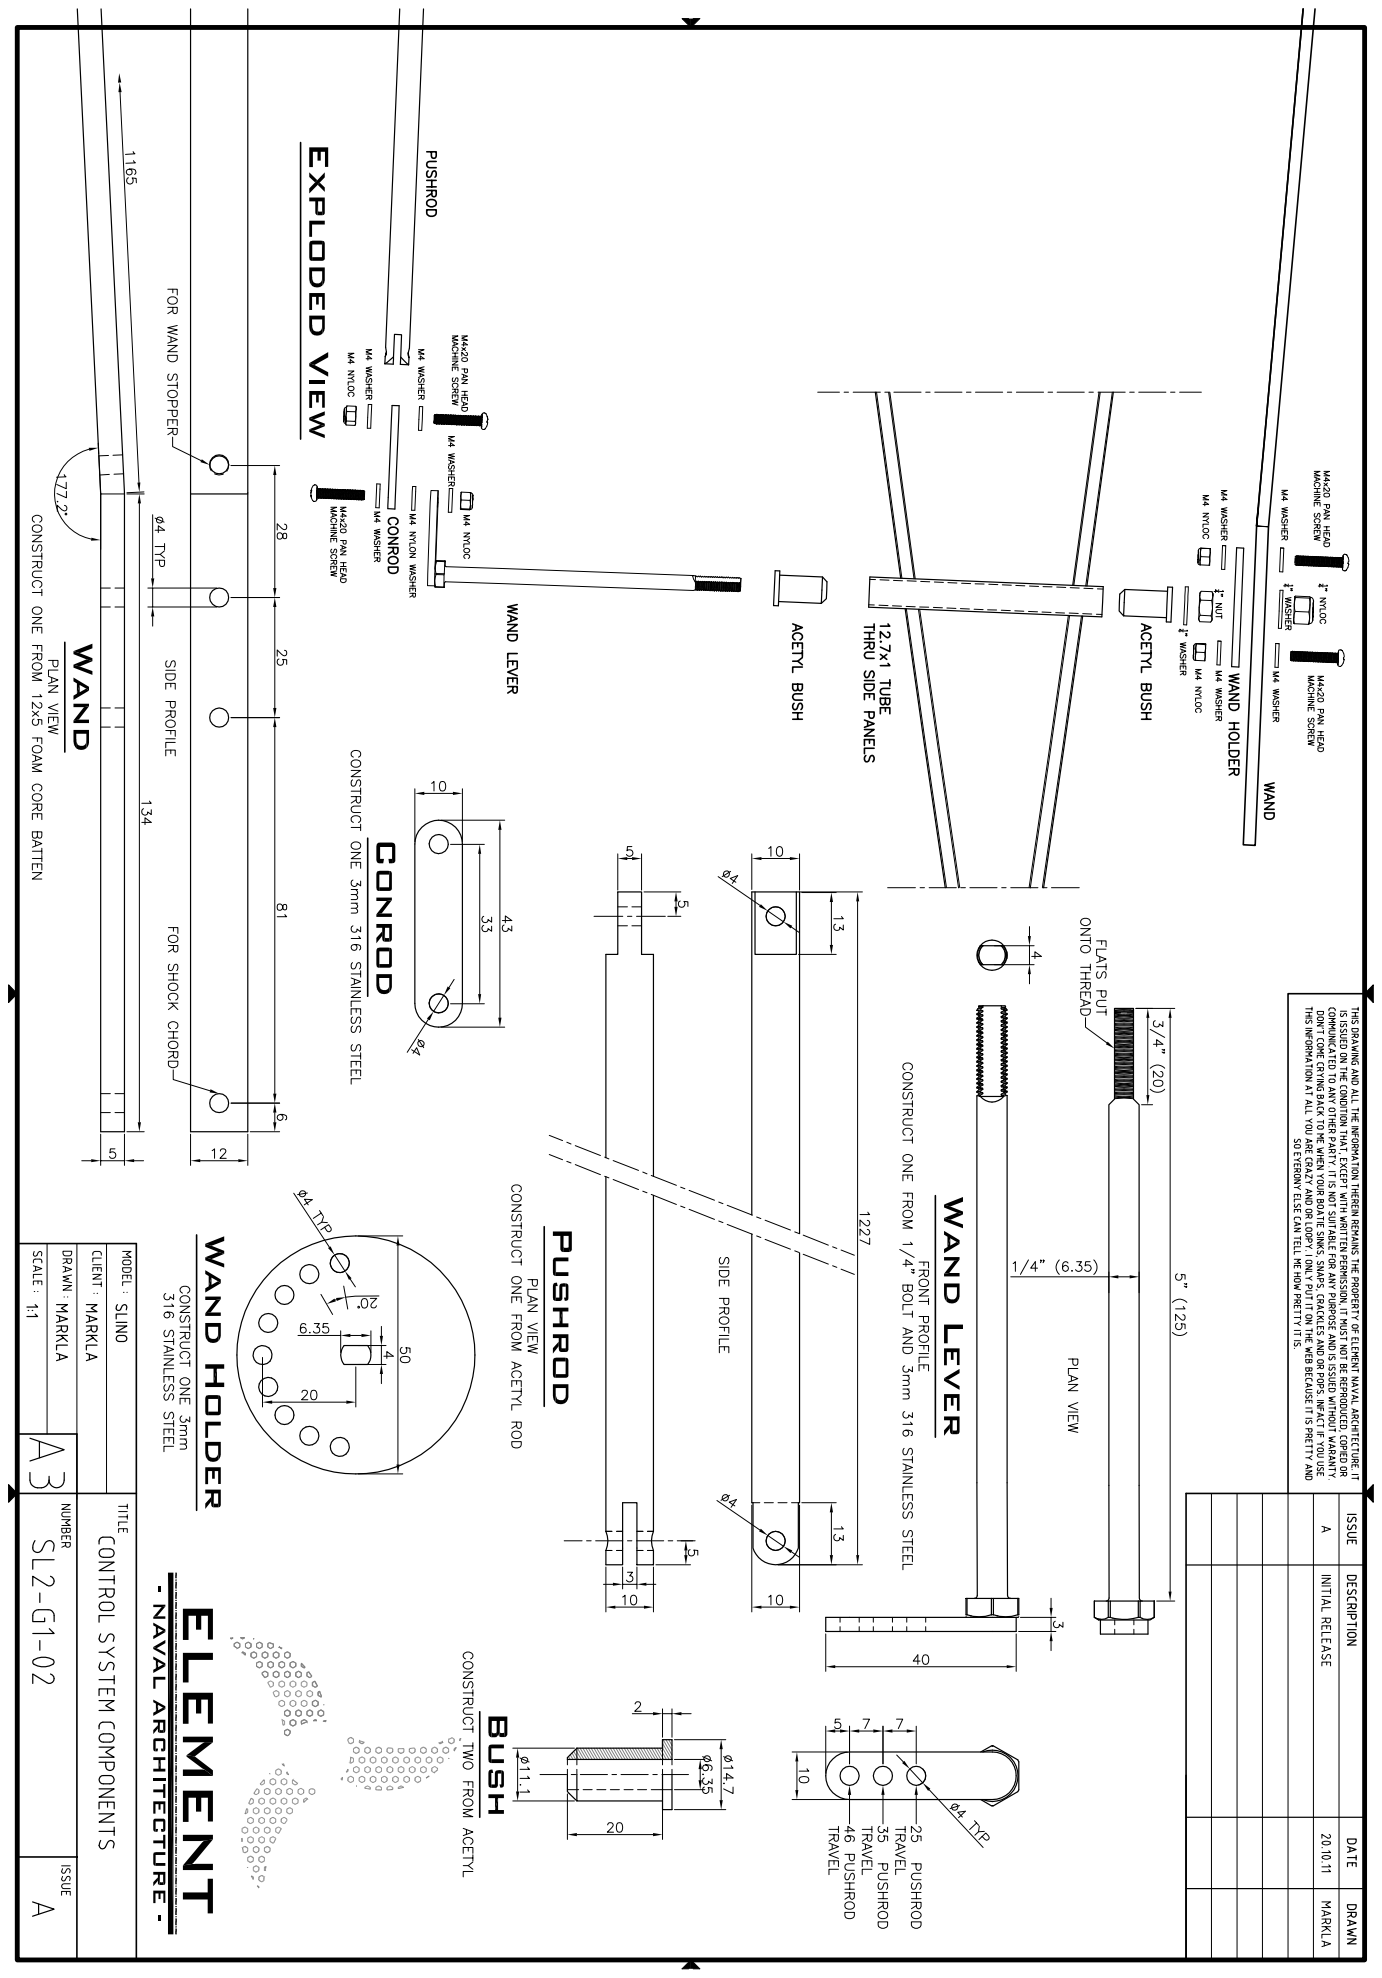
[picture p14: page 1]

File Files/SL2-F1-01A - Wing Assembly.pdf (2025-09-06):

## dia50x1.6

6061 T6

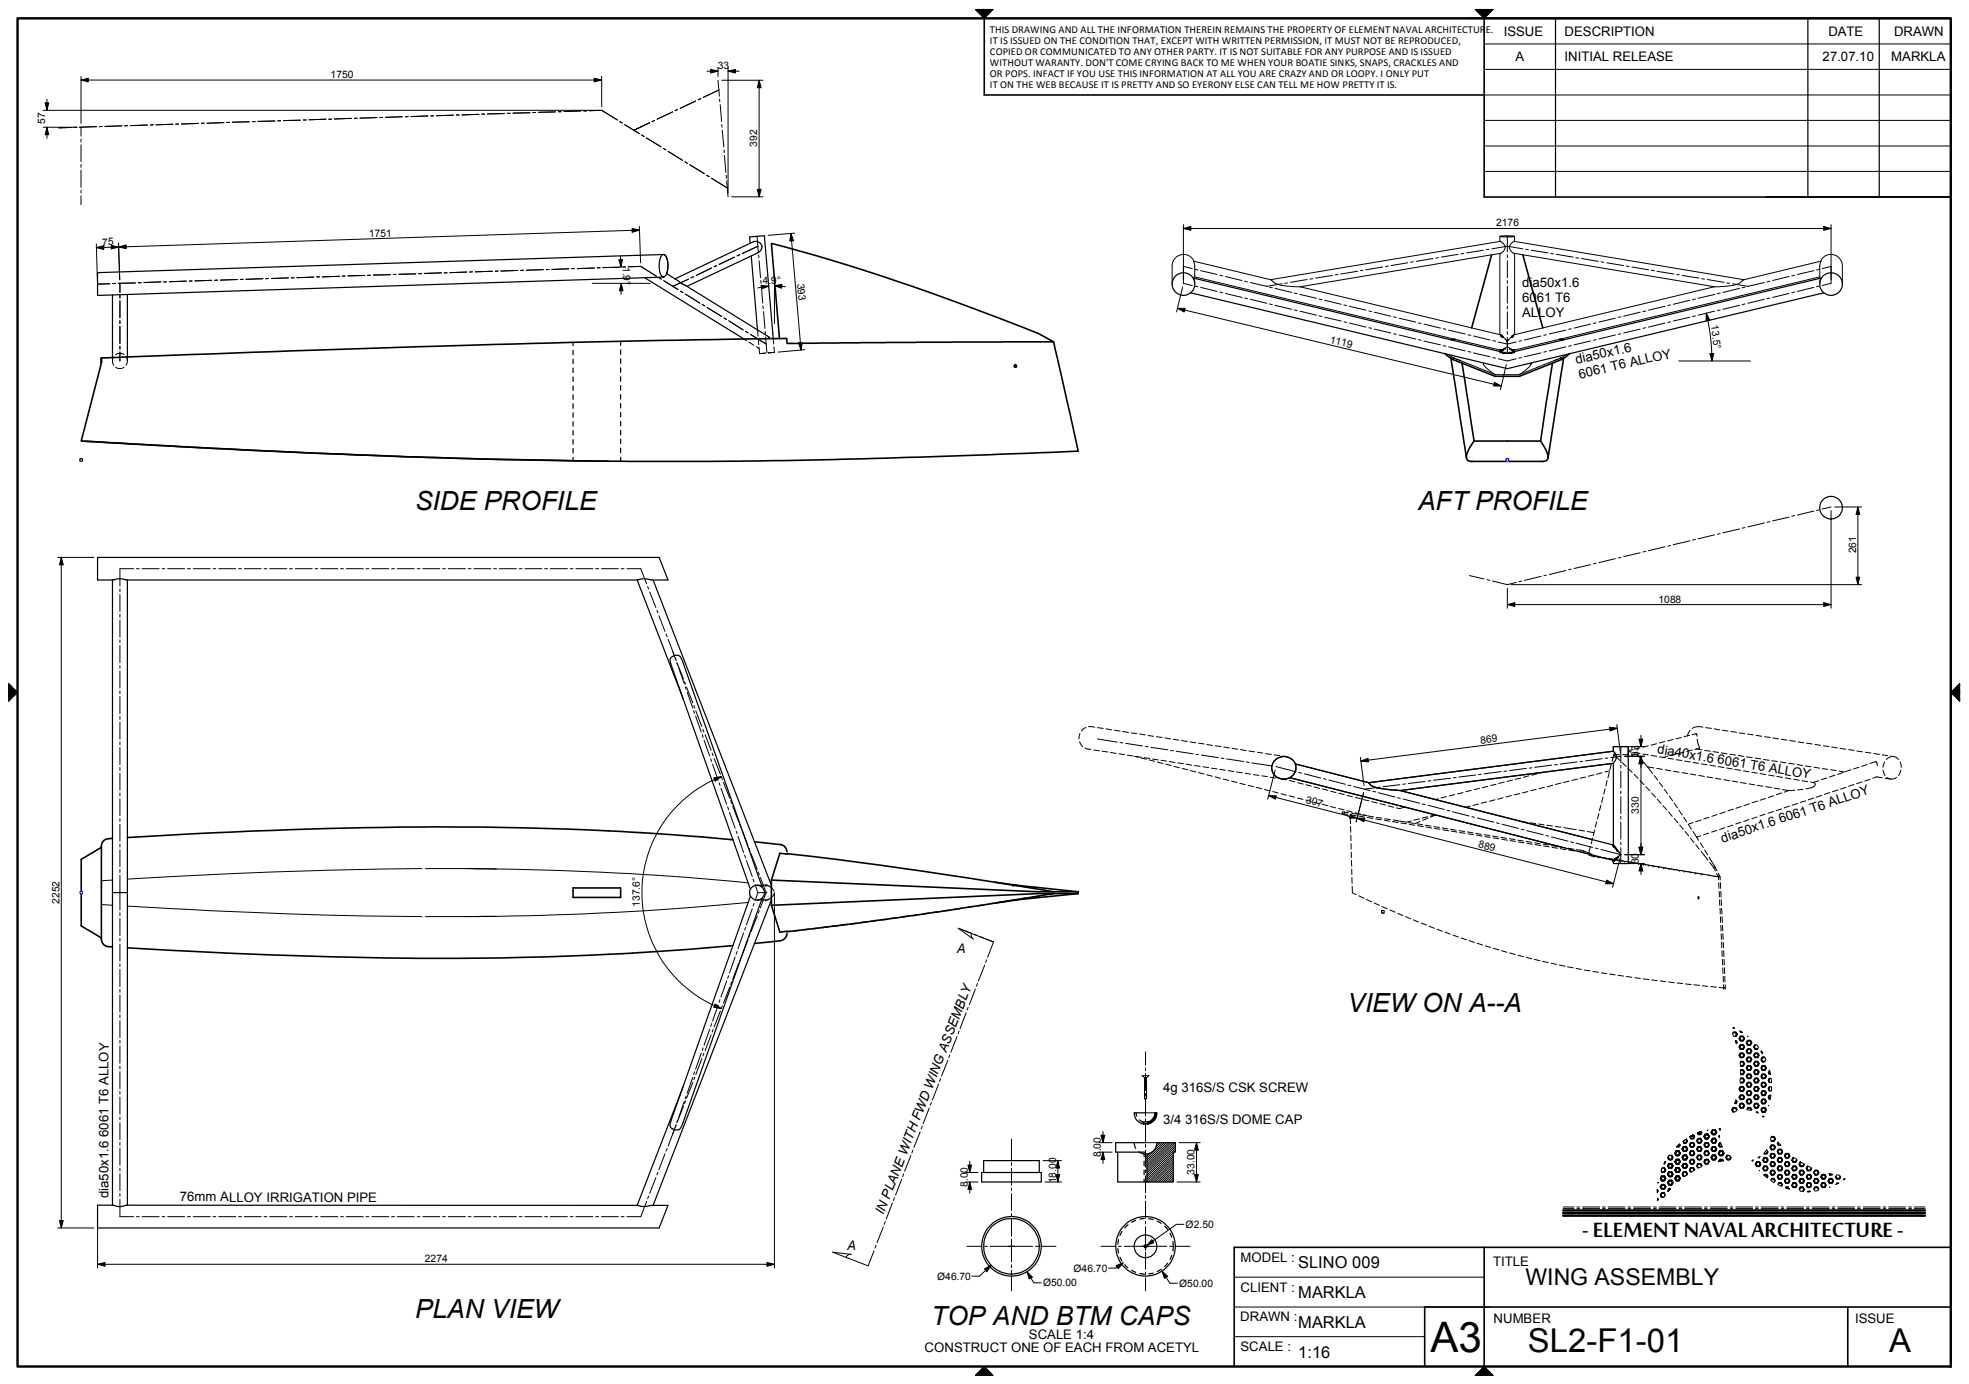
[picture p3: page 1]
3/4 316S/S DOME CAP; AFT PROFILE; SIDE PROFILE; VIEW ON A--A; PLAN VIEW; PLANE; WITH; FWD; dia50x1.6 6061 T6 ALLOY; ALLOY; dia40x1.6 6061 T6 ALLOY; dia; SCALE 1:4; MARKLA; WING ASSEMBLY; SLINO 009; INITIAL RELEASE; MODEL :; SCALE :; TITLE; ISSUE; DESCRIPTION; CLIENT :; DATE; DRAWN; DRAWN :; NUMBER

THIS DRAWING AND ALL THE INFORMATION THEREIN REMAINS THE PROPERTY OF ELEMENT NAVAL ARCHITECTURE.
IT IS ISSUED ON THE CONDITION THAT, EXCEPT WITH WRITTEN PERMISSION, IT MUST NOT BE REPRODUCED,
COPIED OR COMMUNICATED TO ANY OTHER PARTY. IT IS NOT SUITABLE FOR ANY PURPOSE AND IS ISSUED
WITHOUT WARANTY. DON'T COME CRYING BACK TO ME WHEN YOUR BOATIE SINKS, SNAPS, CRACKLES AND
OR POPS. INFACT IF YOU USE THIS INFORMATION AT ALL YOU ARE CRAZY AND OR LOOPY. I ONLY PUT
IT ON THE WEB BECAUSE IT IS PRETTY AND SO EYERONY ELSE CAN TELL ME HOW PRETTY IT IS.

WING ASSEMBLY 4g 316S/S CSK SCREW

76mm ALLOY IRRIGATION PIPE

- ELEMENT NAVAL ARCHITECTURE -

TOP AND BTM CAPS

CONSTRUCT ONE OF EACH FROM ACETYL
